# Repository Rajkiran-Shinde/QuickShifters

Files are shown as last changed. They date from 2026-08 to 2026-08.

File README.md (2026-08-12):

# QuickShifter

### A precision-timed QuickShifter controller built from scratch using STM8S003F3P6

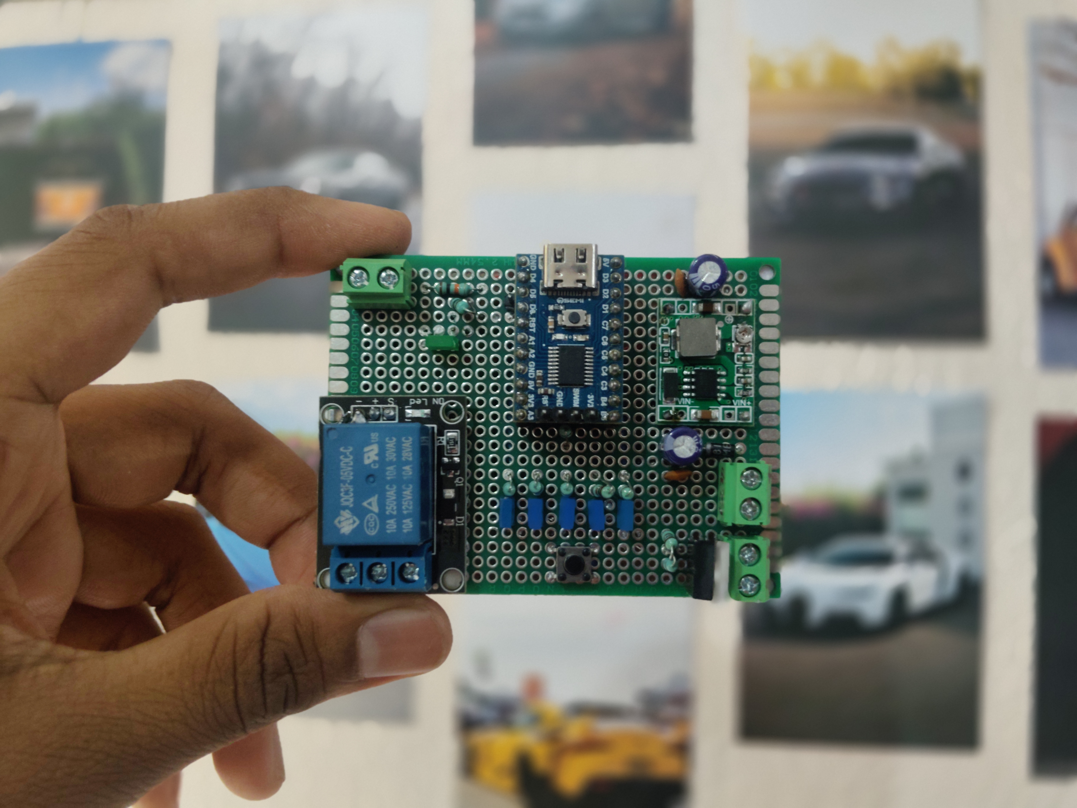
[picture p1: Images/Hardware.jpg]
QuickShifter Hardware


This project started with a simple requirement: build a QuickShifter module that can control a relay for a precisely defined amount of time.

At first, the problem looks almost too simple:

```text
Trigger → Relay ON → Wait → Relay OFF
```

But once the system has to operate reliably on real hardware, timing, switch bounce, repeated triggers, unexpected states, configuration storage, fault recovery, and watchdog behavior all become part of the problem.

This project was built around that idea. Instead of using a blocking delay-based firmware, the QuickShifter was developed as a small, modular embedded system with a timer-driven architecture, state machines, persistent configuration, user feedback, and multiple layers of fault handling.

---

## Project Overview

The QuickShifter uses an **STM8S003F3P6** microcontroller to detect a shift trigger and activate a relay for a selectable cut duration.

Five operating modes are currently available:

| Mode | Cut Time |
| --- | ---: |
| Mode 1 | 40 ms |
| Mode 2 | 50 ms |
| Mode 3 | 60 ms |
| Mode 4 | 70 ms |
| Mode 5 | 80 ms |

The selected mode can be changed using a dedicated button. LEDs indicate the currently selected mode, while a passive buzzer provides audible feedback for startup, mode changes, shifts, ready states, and faults.

The firmware also stores the selected configuration in EEPROM so the selected mode can persist across resets.

The main design goal was to keep the system **small, deterministic, and easy to reason about** rather than using a more powerful microcontroller than the application actually requires.

---

## Hardware

The heart of the system is the **STM8S003F3P6**, running from its internal 16 MHz HSI oscillator. The MCU handles the complete application: input processing, timing, relay control, configuration management, LEDs, buzzer generation, debugging, and watchdog supervision.

The relay is connected to the MCU through the relay-control output and acts as the primary actuator. The shift trigger and mode-selection button use GPIO inputs with internal pull-ups, meaning the inputs remain HIGH when idle and are pulled LOW when the corresponding switch is pressed.

The user interface consists of five individual mode LEDs and a separate RGB status LED. A passive buzzer provides audible feedback and is driven through a BC547 transistor so that the MCU GPIO does not have to directly drive the buzzer load.

The hardware also exposes UART debugging through the STM8 UART1 peripheral. During development, an ESP8266 NodeMCU board was used as a USB-to-UART interface so that debug information could be monitored on a PC.

---

## Hardware Pin Configuration

The current documented hardware allocation is:

| STM8 Pin | Function |
| --- | --- |
| PD2 | Relay output |
| PD3 | QuickShifter trigger input |
| PD4 | Mode-selection button |
| PD5 | UART1 TX |
| PD6 | UART1 RX, currently unused |
| PD6 / A1 / C3 / C4 / C5 | Mode LED outputs as documented in the project |
| PB4 | RGB LED Red |
| PC6 | RGB LED Green |
| PC7 | RGB LED Blue |
| PA3 | Passive buzzer driver |

The exact hardware configuration should always be checked against the latest source files and circuit documentation before building another hardware revision.

---

# Firmware Architecture

The firmware is written in **Embedded C** and is implemented directly around the STM8 peripherals and registers.

There is no Arduino framework involved and no large external firmware framework controlling the application. Hardware functionality is separated into small modules so that the application logic does not need to directly manipulate every peripheral register.

The architecture roughly follows:

```text
                         main()
                           │
                           ▼
                  Application Layer
                           │
              ┌────────────┴────────────┐
              │                         │
              ▼                         ▼
       QuickShifter FSM            Mode Manager
              │                         │
              ├──────────────┐          │
              ▼              ▼          ▼
        Button Driver   Software Timer  EEPROM
              │              │
              └───────┬──────┘
                      ▼
                 Timer Driver
                      │
                      ▼
                   TIM4
                      │
                      ▼
                1 ms System Tick

Additional services:
LED Driver ──► User feedback
Buzzer Driver ──► Audible feedback
UART/Debug ──► Development diagnostics
Watchdog ──► Firmware recovery
```

The main loop is cooperative and non-blocking. Instead of stopping execution for tens of milliseconds while waiting for a relay timer to expire, the firmware starts a software timer and continues executing the rest of the application.

This allows the buttons, state machine, buzzer, and watchdog to continue operating while the relay timing is in progress.

---

# Clock and Timer System

The STM8S003F3 initially operates from its internal **16 MHz HSI oscillator** with a default divider. The firmware configures the clock divider so that the MCU operates at the full 16 MHz.

```c
CLK_CKDIVR = 0x00;
```

The system uses **TIM4** as the main timing foundation.

TIM4 is configured with:

```text
CPU Clock     : 16 MHz
Prescaler     : 128
Timer Clock   : 125 kHz
Auto Reload   : 124
Tick          : 1 ms
```

Every TIM4 update interrupt increments a global system tick.

```c
volatile uint32_t system_tick;
```

This provides a common time reference for the rest of the firmware.

The important idea here is that the QuickShifter does not depend on large blocking delays such as:

```c
Timer_Delay(70);
```

for application timing.

Instead, the firmware can start a timer and check whether it has expired while continuing to execute other tasks.

---

# Software Timer

The software timer module is built on top of the 1 ms system tick.

A software timer contains:

```c
typedef struct
{
    uint32_t start_time;
    uint32_t duration;
    uint8_t active;

} SoftwareTimer_t;
```

The main API is:

```c
SoftwareTimer_Start();
SoftwareTimer_Stop();
SoftwareTimer_Expired();
SoftwareTimer_IsRunning();
```

This allows multiple independent timing operations to exist without requiring a separate hardware timer for every function.

For example, the relay cut timer and cooldown timer can use the same system tick while remaining logically independent.

---

# QuickShifter State Machine

The QuickShifter itself is implemented as a **finite state machine** rather than a collection of unrelated delays and `if` statements.

The normal operating sequence is:

```text
                 ┌──────────────┐
                 │     IDLE     │
                 └──────┬───────┘
                        │
                  Shift detected
                        │
                        ▼
                 ┌──────────────┐
                 │ CUT_ACTIVE   │
                 └──────┬───────┘
                        │
                   Timer expires
                        │
                        ▼
                 ┌──────────────┐
                 │  COOLDOWN    │
                 └──────┬───────┘
                        │
                 Cooldown expires
                        │
                        ▼
                 ┌──────────────┐
                 │ WAIT_RELEASE │
                 └──────┬───────┘
                        │
                  Button released
                        │
                        ▼
                 ┌──────────────┐
                 │     IDLE     │
                 └──────────────┘
```

The firmware also contains fault handling that forces the system toward a known safe condition.

The main QuickShifter task is implemented through:

```c
QuickShifter_Init();
QuickShifter_Task();
```

When a valid shift is detected, the relay is activated and the selected cut-time timer is started.

When that timer expires, the relay is explicitly turned OFF.

After that, the firmware enters a cooldown period before waiting for the original trigger to be released.

This prevents one long button press or mechanical vibration from producing multiple cuts.

The important safety principle throughout the state machine is:

```text
Unexpected condition
        ↓
    Relay OFF
        ↓
  Known firmware state
```

---

# Button Driver

Mechanical buttons do not produce a perfectly clean HIGH-to-LOW transition. They bounce electrically for a short period when pressed or released.

The button driver therefore uses its own state machine:

```text
RELEASED
    │
    ▼
DEBOUNCE_PRESS
    │
    ▼
PRESSED
    │
    ▼
DEBOUNCE_RELEASE
    │
    ▼
RELEASED
```

A software timer is used for the debounce period rather than blocking the CPU.

The button module provides:

```c
Button_Init();
Button_Update();
Button_GetPress();

ModeButton_Init();
ModeButton_Update();
ModeButton_GetPress();
```

The driver also converts a physical press into a one-shot logical event. This means one physical button press produces one application event instead of repeatedly triggering the QuickShifter while the button remains pressed.

---

# Operating Modes

The QuickShifter supports five selectable cut durations:

```text
Mode 1 → 40 ms
Mode 2 → 50 ms
Mode 3 → 60 ms
Mode 4 → 70 ms
Mode 5 → 80 ms
```

The mode manager is implemented in:

```text
mode.c
mode.h
```

The main functions are:

```c
Mode_Init();
Mode_Next();
Mode_Get();
Mode_GetCutTime();
```

The modes wrap around continuously:

```text
Mode 1
  ↓
Mode 2
  ↓
Mode 3
  ↓
Mode 4
  ↓
Mode 5
  ↓
Mode 1
```

The selected mode is kept separate from the actual timer implementation. The mode manager decides **what timing should be used**, while the timer system is responsible for **measuring that timing**.

This separation makes the firmware easier to modify and test.

---

# EEPROM Configuration

The selected mode is stored in the STM8 EEPROM so that configuration can persist between resets.

The EEPROM implementation does more than simply write a number and hope for the best.

The configuration contains a magic value, mode value, and checksum. The firmware validates the stored information before accepting it.

Conceptually:

```text
Read EEPROM
     │
     ├── Magic
     ├── Mode
     └── Checksum
           │
           ▼
      Validate data
           │
      ┌────┴────┐
      ▼         ▼
   Valid      Invalid
      │         │
      ▼         ▼
   Accept    Default mode
```

The checksum is calculated from the stored configuration, allowing simple data corruption to be detected.

The firmware also verifies EEPROM writes by reading the data back after programming.

An important part of the implementation is that the watchdog remains active during blocking EEPROM operations. Instead of disabling the watchdog while EEPROM operations are taking place, the EEPROM driver services the watchdog during the operation.

---

# Watchdog and Fault Handling

The STM8 Independent Watchdog provides a final recovery mechanism if the firmware becomes stuck.

The application initializes and refreshes it using:

```c
Watchdog_Init();
Watchdog_Refresh();
```

The normal main loop continuously refreshes the watchdog.

If the firmware becomes trapped in an unexpected infinite loop or otherwise stops servicing the watchdog, the IWDG eventually resets the MCU.

The watchdog is not being used as a replacement for proper firmware design. It is the last line of defense against firmware execution failure.

The project also includes deliberate watchdog fault-injection testing where watchdog refreshing was intentionally stopped to verify that the MCU actually resets.

Another important detail is that blocking EEPROM and UART operations were made watchdog-aware. This prevents legitimate lengthy operations from accidentally causing a watchdog reset while still allowing the watchdog to recover the system from a genuine firmware lock-up.

---

# LED Driver

The LED subsystem provides visual feedback without requiring an external GPIO expander.

Five LEDs represent the five QuickShifter modes:

```text
Mode 1 → 40 ms
Mode 2 → 50 ms
Mode 3 → 60 ms
Mode 4 → 70 ms
Mode 5 → 80 ms
```

The LED functionality is contained in:

```text
led.c
led.h
```

The main interface includes:

```c
LED_Init();
LED_Mode_Display();
```

A separate RGB LED provides system-level status indication.

The RGB channels are controlled directly through STM8 GPIO pins, keeping the implementation simple and deterministic.

---

# Passive Buzzer

The project uses a **passive buzzer** rather than simply switching an active buzzer ON and OFF.

A passive buzzer requires an alternating waveform, so the firmware generates a square wave whose frequency determines the perceived pitch.

The final design uses a **BC547 NPN transistor** as a low-side driver between the MCU and the buzzer.

```text
STM8 GPIO
    │
   1 kΩ
    │
 BC547 Base
    │
 BC547 Collector
    │
 Passive Buzzer
    │
   +5V
```

The buzzer waveform is generated using **TIM2**. The timer interrupt toggles the buzzer output, producing the required square wave.

The buzzer software also contains a small melody engine based on notes containing:

```c
frequency
duration
```

This allows events such as startup, mode changes, quick shifts, ready status, and faults to have their own audible feedback.

The melody engine is designed to be non-blocking so that audio feedback does not interfere with the QuickShifter timing logic.

The main buzzer functions include:

```c
Buzzer_Init();
Buzzer_Play();
Buzzer_Task();
Buzzer_TickISR();
```

---

# UART Debugging

During development, UART was added to make firmware behavior easier to observe.

The debug architecture is separated into two layers:

```text
Application
    ↓
debug.c / debug.h
    ↓
uart.c / uart.h
    ↓
STM8 UART1
```

This means application code can use:

```c
Debug_Log();
Debug_LogState();
Debug_LogShift();
Debug_LogMode();
```

without directly accessing UART registers.

The current UART debug configuration is:

```text
Baud Rate : 9600
Data      : 8 bits
Parity    : None
Stop      : 1
```

UART debugging was tested using an ESP8266 NodeMCU board as a temporary USB-to-UART interface and monitored on a PC.

Debugging can also be disabled for a production build using the debug configuration macro, allowing the application to remain independent from the development UART interface.

---

# Main Application Flow

The main application initializes the system in a controlled sequence:

```text
Clock
  ↓
Timer
  ↓
Buttons
  ↓
Mode Button
  ↓
Debug
  ↓
LED
  ↓
Buzzer
  ↓
EEPROM
  ↓
Mode
  ↓
QuickShifter
  ↓
Watchdog
  ↓
Main Loop
```

The main loop then continuously services the different modules:

```c
while(1)
{
    Button_Update();
    ModeButton_Update();

    QuickShifter_Task();

    Buzzer_Task();

    Watchdog_Refresh();
}
```

Mode changes are handled as events. When a valid mode-button press is detected, the firmware advances to the next mode, updates the mode LED, plays the corresponding buzzer feedback, and reports the new configuration through the debug interface when debugging is enabled.

---

# Software Stack

The project is intentionally lightweight and close to the hardware.

**Language:** Embedded C

**Target MCU:** STM8S003F3P6

**Clock:** 16 MHz internal HSI

**Hardware peripherals:** GPIO, TIM4, TIM2, UART1, EEPROM, Independent Watchdog

**Firmware architecture:** Modular, cooperative, non-blocking application with finite state machines and software timers

**Debug interface:** UART1 → USB-UART → PC

**User interface:** Push buttons, five mode LEDs, RGB status LED and passive buzzer

The repository contains the STM8 development project files and the complete C/H source modules used to implement the firmware.

---

# Source Code Structure

The repository is divided into small modules instead of keeping the complete firmware inside `main.c`.

```text
QuickShifters/
│
├── images/
│   └── Hardware.jpg
│
├── main.c
│
├── gpio.c / gpio.h
├── clock.c / clock.h
├── timer.c / timer.h
├── software_timer.c / software_timer.h
│
├── button.c / button.h
├── quickshifter.c / quickshifter.h
├── mode.c / mode.h
│
├── relay.c / relay.h
├── led.c / led.h
├── buzzer.c / buzzer.h
│
├── eeprom.c / eeprom.h
├── watchdog.c / watchdog.h
│
├── uart.c / uart.h
├── debug.c / debug.h
│
├── stm8_hw.h
├── stm8_interrupt_vector.c
├── common.h
├── config.h
│
├── 01_GPIO.md
├── 02_stateMachine.md
├── 03_ModeSelection.md
├── 04_firmwareSafety.md
├── 05_led&Buzzer_Driver.md
└── pin_config.md
```

The individual modules have clear responsibilities.

`quickshifter.c` contains the core QuickShifter state machine. `button.c` handles physical input and debouncing. `mode.c` handles the five operating modes. `software_timer.c` provides reusable timing functionality on top of the system tick.

`relay.c`, `led.c`, and `buzzer.c` handle the physical outputs, while `eeprom.c` manages persistent configuration. `watchdog.c` handles the Independent Watchdog and `debug.c`/`uart.c` provide the development-time debugging interface.

This separation keeps the application logic independent from most low-level hardware details.

---

# Important Firmware APIs

Some of the main interfaces exposed by the firmware are:

```c
// Clock
CLK_Init();

// Timer
Timer_Init();
Timer_GetTick();
Timer_Delay();

// Software Timer
SoftwareTimer_Start();
SoftwareTimer_Stop();
SoftwareTimer_Expired();
SoftwareTimer_IsRunning();

// Buttons
Button_Init();
Button_Update();
Button_GetPress();

ModeButton_Init();
ModeButton_Update();
ModeButton_GetPress();

// QuickShifter
QuickShifter_Init();
QuickShifter_Task();

// Modes
Mode_Init();
Mode_Next();
Mode_Get();
Mode_GetCutTime();

// EEPROM
EEPROM_Init();

// LEDs
LED_Init();
LED_Mode_Display();

// Buzzer
Buzzer_Init();
Buzzer_Play();
Buzzer_Task();
Buzzer_TickISR();

// Watchdog
Watchdog_Init();
Watchdog_Refresh();

// Debug
Debug_Init();
Debug_Log();
Debug_LogState();
Debug_LogShift();
Debug_LogMode();
```

These interfaces allow the application layer to interact with the hardware modules without directly depending on their internal implementation.

---

# Safety Philosophy

The most important design rule in the firmware is simple:

> **If something unexpected happens, the relay should end up OFF.**

This principle appears in multiple places in the firmware.

During startup, the relay is initialized into a known state. During normal operation, the relay is explicitly turned OFF when the cut timer expires. During invalid state recovery, the relay is also forced OFF before the state machine returns to a known state.

Other layers provide additional protection:

```text
Button noise
    ↓
Debounce

Repeated trigger
    ↓
One-shot event + state machine

Relay timing
    ↓
Software timer

Rapid retriggering
    ↓
Cooldown

Held trigger
    ↓
WAIT_RELEASE

Invalid configuration
    ↓
EEPROM validation

Firmware lock-up
    ↓
Independent Watchdog
```

The intention is not to make the firmware complicated for the sake of complexity. Each layer exists because it solves a different failure mode.

---

# Development and Testing

The firmware was developed incrementally rather than attempting to build the complete system in one step.

The initial hardware verified basic GPIO operation and relay control. The firmware was then moved from blocking delays to a timer-driven architecture. TIM4 was verified using the system tick, and the software timer system was introduced.

The QuickShifter state machine and non-blocking button driver were then added, followed by the five configurable modes and EEPROM persistence.

UART debugging was added to make development and troubleshooting easier. The LED and buzzer system was developed separately and integrated into the main application afterward.

The watchdog was also tested through deliberate fault injection to confirm that a firmware execution failure results in an MCU reset.

During development, several real hardware/firmware issues were encountered and resolved, including GPIO abstraction problems, buzzer drive limitations, timer/interrupt behavior, EEPROM interaction with the watchdog, and UART debugging configuration.

This repository contains the development notes documenting those stages in more detail.

---

# Documentation

The project includes dedicated documentation for the major firmware subsystems:

* [`01_GPIO.md`](01_GPIO.md) — GPIO abstraction and hardware configuration
* [`02_stateMachine.md`](02_stateMachine.md) — Timer architecture, software timers, state machines and non-blocking firmware
* [`03_ModeSelection.md`](03_ModeSelection.md) — UART debugging, mode selection and configurable timing
* [`04_firmwareSafety.md`](04_firmwareSafety.md) — Safety, EEPROM validation, watchdog and fault handling
* [`05_led&Buzzer_Driver.md`](05_led%26Buzzer_Driver.md) — LED and passive buzzer architecture
* [`pin_config.md`](pin_config.md) — Hardware pin allocation

These documents provide a deeper look into how the firmware evolved and why particular implementation decisions were made.

---

# What Makes This Project Interesting?

The interesting part of this project isn't really the relay.

It's the engineering around it.

The system takes a simple real-world requirement and turns it into a small embedded architecture with deterministic timing, state-based control, persistent configuration, hardware feedback, debugging infrastructure and recovery mechanisms.

Instead of:

```text
Button
  ↓
delay()
  ↓
Relay
```

the final architecture is closer to:

```text
Physical Input
      ↓
Debounce State Machine
      ↓
One-Shot Event
      ↓
QuickShifter State Machine
      ↓
Software Timer
      ↓
Relay Control
      ↓
Cooldown
      ↓
Wait for Release
      ↓
Ready for Next Shift
```

And running alongside it are the watchdog, configuration system, LEDs, buzzer and debug infrastructure.

That was the main goal of the project: **not just making the relay work, but making the system behave predictably when the real world inevitably does something unexpected.**

---

# Current Status

The first working prototype has been developed and the core firmware architecture is operational.

The current implementation includes the five selectable cut modes, non-blocking timing, QuickShifter and button state machines, EEPROM configuration, watchdog supervision, LED feedback, buzzer feedback and UART debugging.

Further hardware refinement, validation and production-oriented improvements can be added as the project moves beyond the prototype stage.

---

## Author

**Rajkiran Shinde**

Embedded Systems | Firmware | Electronics

[GitHub](https://github.com/Rajkiran-Shinde)
---

## Disclaimer

This repository documents an embedded prototype developed for a real-world application. The firmware and hardware should be validated thoroughly against the final electrical and mechanical system before being used in a safety-critical or production environment.

---

### Built with C, registers, timers, state machines... and a questionable amount of debugging. 😄

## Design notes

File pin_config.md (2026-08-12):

PD2 ----> Relay output 
PD3 ----> Trigger input (D3 to GND)
PD4 ----> Mode Selection pin (D4--GND)
PD5 ----> UART1 TX 

Mode LED's 
Mode 1 --> D6
Mode 2 --> A1
Mode 3 --> C3
Mode 4 --> C4
Mode 5 --> C5

System Led 
Red --> B4
Green --> C6
Blue --> C7

Buzzer --> A32

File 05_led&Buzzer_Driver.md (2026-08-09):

# QuickShifter — LED Driver & Buzzer Driver Documentation

## 1. Overview

The QuickShifter firmware uses two independent user-interface subsystems:

1. **LED Driver**

   * Displays the currently selected QuickShifter mode.
   * Provides system/status indication.
   * Uses discrete GPIO outputs rather than an external I/O expander.

2. **Buzzer Driver**

   * Provides audible feedback during system startup.
   * Indicates QuickShifter mode changes.
   * Provides audible feedback when a quick-shift is detected.
   * Provides ready/fault indication.
   * Uses a passive buzzer driven through a **BC547 transistor**.
   * Generates tones using **TIM2** and software-controlled GPIO toggling.
   * Uses a non-blocking melody engine so audio feedback does not interfere with QuickShifter timing.

The design was intentionally kept lightweight and deterministic because the QuickShifter's primary function is timing-critical relay control.

---

# 2. LED Driver

## 2.1 Design Objective

The LED subsystem was designed to provide visual feedback without introducing an external GPIO expander such as the MCP23008.

Initially, an I/O expander and LED matrix were considered because the system contains multiple LEDs.

The final architecture uses the STM8 GPIO pins directly.

This was selected because:

* The number of required outputs was manageable.
* The LEDs can operate from the MCU's logic voltage with appropriate current limiting.
* An external I/O expander would add unnecessary hardware and software complexity.
* A 3×3 LED matrix would require additional scanning logic and six GPIO pins while only providing limited savings.
* Direct GPIO control provides simpler and more deterministic firmware.

---

# 3. LED Hardware Architecture

The system contains:

### Mode LEDs

Five LEDs are used to represent the five QuickShifter modes:

| LED | Function |
| --- | --- |
| Mode LED 1 | 40 ms |
| Mode LED 2 | 50 ms |
| Mode LED 3 | 60 ms |
| Mode LED 4 | 70 ms |
| Mode LED 5 | 80 ms |

The selected mode is displayed by activating the corresponding LED.

The mode timing relationship is:

```text
Mode 1 ? 40 ms
Mode 2 ? 50 ms
Mode 3 ? 60 ms
Mode 4 ? 70 ms
Mode 5 ? 80 ms
```

This gives the user an immediate visual indication of the selected cut duration.

---

# 4. Status RGB LED

A separate RGB LED provides overall system status.

The final GPIO mapping is:

```text
RED   ? PB4
GREEN ? PC6
BLUE  ? PC7
```

This LED is independent of the five mode LEDs.

It can therefore be used for system-level states such as:

```text
OFF      ? System inactive / no status
RED      ? Fault / error
GREEN    ? Ready / normal
BLUE     ? System or operating indication
```

The exact status-state mapping can be extended later without changing the basic driver architecture.

---

# 5. LED Driver Software Architecture

The LED functionality was consolidated into:

```text
led.h
led.c
```

rather than creating separate files such as:

```text
mode_led.c
status_led.c
```

This was intentionally done because both are fundamentally GPIO-based LED functions.

The architecture is therefore:

```text
                LED DRIVER
                    ¦
          +-------------------+
          ¦                   ¦
      Mode LEDs          Status RGB LED
          ¦                   ¦
      5 outputs          R / G / B
```

---

# 6. LED Initialization

The LED driver contains an initialization routine:

```c
LED_Init();
```

This configures all LED GPIO pins as outputs and establishes a known initial state.

The initialization sequence is performed during system startup.

Conceptually:

```text
MCU Reset
   ?
Clock initialization
   ?
Timer initialization
   ?
Button initialization
   ?
LED_Init()
   ?
LED outputs configured
```

This prevents the LEDs from remaining in an undefined state after reset.

---

# 7. Mode LED Display

The mode LED driver provides a function similar to:

```c
LED_Mode_Display(mode);
```

The mode number is converted into the corresponding LED output.

For example:

```text
LED_Mode_Display(1)
       ?
Mode 1 LED ON
```

and:

```text
LED_Mode_Display(5)
       ?
Mode 5 LED ON
```

The selected mode is therefore directly visible to the user.

---

# 8. Mode Selection Integration

The mode display is updated whenever the mode button produces a valid press event.

The main application follows this sequence:

```text
Mode button pressed
        ?
Debounce
        ?
ModeButton_GetPress()
        ?
Mode_Next()
        ?
LED_Mode_Display()
        ?
Buzzer_Play(MODE_CHANGE)
```

This creates a combined visual + audible user interface.

---

# 9. GPIO Port A Issue Discovered During Development

One important debugging issue occurred while implementing the buzzer and GPIO abstraction.

The initial GPIO driver supported:

```text
PORT_B
PORT_C
PORT_D
```

but did not correctly implement:

```text
PORT_A
```

When the buzzer was moved to PA3, the GPIO abstraction did not correctly map the Port A registers.

The result was that a request such as:

```c
GPIO_Output_PP(PORT_A, PIN3);
```

did not actually configure the PA3 registers correctly.

This caused PA3 not to reach the expected output voltage.

The issue was solved by adding the STM8S003F3 Port A registers:

```text
PA_ODR
PA_IDR
PA_DDR
PA_CR1
PA_CR2
```

and adding `PORT_A` handling to the GPIO register-selection functions.

This was an important firmware-level hardware abstraction bug.

---

# 10. Buzzer Driver

## 10.1 Objective

The buzzer subsystem was designed to provide an audible interface without blocking the QuickShifter control loop.

The required events were:

* Boot
* Mode change
* Quick shift
* Ready
* Fault

Instead of simply turning the buzzer ON/OFF for arbitrary delays, a reusable **melody engine** was implemented.

---

# 11. Passive Buzzer

The project uses a:

```text
Passive buzzer
```

A passive buzzer requires an alternating electrical signal.

Therefore, the STM8 does not simply set the buzzer GPIO HIGH.

Instead, the firmware generates a square wave.

For example:

```text
       +-----+     +-----+
HIGH   ¦     ¦     ¦     ¦
       ¦     ¦     ¦     ¦
LOW ---+     +-----+     +-----
```

The frequency of this waveform determines the perceived pitch.

---

# 12. Initial Direct GPIO Buzzer Drive

Initially, the passive buzzer was connected directly to the STM8 GPIO.

This worked electrically, but the output volume was very low.

The same buzzer was then tested using an Arduino Uno.

The Arduino produced significantly louder sound.

This demonstrated that:

```text
Buzzer itself ? functional
```

and the problem was related to the STM8-side drive.

---

# 13. BC547 Driver

To solve the low-volume problem, a BC547 NPN transistor was added as a low-side driver.

The final architecture is:

```text
                  +5V
                   ¦
                   ¦
               Passive
                Buzzer
                   ¦
                   ¦
                   C
                +-----+
STM8 PA3 --1k--?¦ B   ¦
                ¦BC547¦
                ¦     ¦
                +--E--+
                   ¦
                  GND
```

The STM8 does **not** directly power the buzzer anymore.

Instead:

```text
PA3
 ?
1 kO resistor
 ?
BC547 base
 ?
BC547 switches buzzer current
```

The transistor therefore isolates the MCU GPIO from the buzzer load and provides significantly stronger drive.

---

# 14. Common Ground

The STM8 and buzzer supply must share a common ground:

```text
STM8 GND
   ¦
   +-------- Buzzer supply GND
   ¦
   +-------- BC547 emitter
```

Without a common reference, the transistor control signal would not have a reliable voltage reference.

---

# 15. Buzzer GPIO

The final buzzer GPIO is:

```text
PA3
```

The configuration is:

```c
#define BUZZER_PORT    PORT_A
#define BUZZER_PIN     PIN3
```

PA3 is configured as a push-pull output.

The signal from PA3 drives the BC547 base through the base resistor.

---

# 16. Why PB5 Was Abandoned

The buzzer was initially tested using PB5.

However, PB5 on the STM8S003F3 is a true open-drain pin.

That made it unsuitable for the direct push-pull buzzer waveform we wanted.

Therefore, the buzzer was moved to:

```text
PA3
```

and configured as a push-pull output.

This was a hardware-specific STM8 pin-selection decision.

---

# 17. TIM2 Tone Generation

The buzzer uses **TIM2** to generate its waveform.

The STM8 system clock is operating at:

```text
16 MHz
```

TIM2 is configured with a prescaler of:

```text
/8
```

Therefore:

```text
16 MHz / 8 = 2 MHz
```

timer clock.

The buzzer GPIO is toggled once per timer overflow.

Therefore the output frequency is approximately:

```text
Fout = TimerClock / (2 × ARR)
```

or:

```text
Fout = 2,000,000 / (2 × ARR)
```

This produces the required audible square wave.

---

# 18. TIM2 Interrupt Architecture

TIM2 generates an update interrupt.

The interrupt vector is:

```c
INTERRUPT_HANDLER(
    TIM2_UPD_OVF_BRK_IRQHandler,
    13
)
{
    Buzzer_TickISR();
}
```

The architecture is:

```text
TIM2 overflow
      ?
TIM2 interrupt
      ?
IRQ 13
      ?
Buzzer_TickISR()
      ?
Clear interrupt flag
      ?
Toggle PA3
      ?
BC547
      ?
Passive buzzer
```

---

# 19. Important TIM2 Watchdog Issue

During development, enabling the TIM2 interrupt initially caused the STM8 watchdog to reset the MCU.

The debugging process isolated the problem.

The following test worked:

```c
TIM2_IER |= TIM2_IER_UIE;
```

while the ISR only cleared the TIM2 update flag.

This confirmed that:

* TIM2 configuration was functional.
* TIM2 was running.
* The interrupt was reaching the MCU.
* The interrupt flag could be cleared.
* The watchdog problem was related to the original ISR/output handling rather than TIM2 itself.

The final ISR became:

```c
void Buzzer_TickISR(void)
{
    TIM2_SR1 &= (uint8_t)(~TIM2_SR_UIF);

    GPIO_Toggle(
        BUZZER_PORT,
        BUZZER_PIN
    );
}
```

This successfully generates the buzzer waveform.

---

# 20. Buzzer Melody Engine

Instead of hardcoding delays, the buzzer uses a note structure:

```c
typedef struct
{
    uint16_t frequency;
    uint16_t duration;

} BuzzerNote;
```

Each note contains:

```text
frequency
duration
```

For example:

```c
{ 800, 100 }
```

means:

```text
800 Hz
100 ms
```

---

# 21. REST and End Markers

Two special values are used.

### REST

```c
#define BUZZER_REST 0
```

A REST means:

```text
No sound
```

The timer is stopped and the buzzer output is forced LOW.

### End of melody

```c
#define BUZZER_MELODY_END 0xFFFF
```

This tells the melody engine that the sequence has finished.

---

# 22. Current Tone Range

After testing several frequencies, the current preferred range was established as:

```c
#define TONE_LOW   800
#define TONE_MID   1000
#define TONE_HIGH  1200
```

This range was selected based on actual listening tests with the installed buzzer and BC547 driver.

Higher frequencies such as:

```text
1800 Hz
2200 Hz
2600 Hz
3000+ Hz
```

were found to sound sharper and more aggressive.

The 800–1200 Hz range provides a more comfortable sound for this application.

---

# 23. Boot Melody

The boot melody follows the original musical concept developed during the project.

Current sequence:

```text
800 Hz
   ?
1000 Hz
   ?
1200 Hz
   ?
1000 Hz
```

It provides a rising startup signature followed by a settling tone.

Conceptually:

```text
DO ? MID ? HIGH ? MID
```

---

# 24. Mode Change Melody

The mode-change melody is:

```text
1000 Hz
   ?
1200 Hz
```

It provides a short confirmation that the selected QuickShifter mode has changed.

The mode change therefore provides:

```text
Button press
     ?
Mode changes
     ?
Mode LED changes
     ?
Buzzer confirmation
```

---

# 25. QuickShift Melody

The QuickShift beep is deliberately short.

The current implementation uses:

```text
1200 Hz
˜45 ms
```

This produces a short audible confirmation when the shift input is detected.

---

# 26. QuickShift Integration

The buzzer was integrated into `quickshifter.c`.

When a valid shift event is detected:

```c
if(Button_GetPress())
{
    Buzzer_Play(BUZZER_EVENT_SHIFT);

    Relay_On();

    ...
}
```

The important design decision is that **the buzzer does not delay the relay operation**.

The sequence is:

```text
Valid shift detected
       ¦
       +--------? Start buzzer
       ¦
       +--------? Relay ON
                       ¦
                       ?
                  40–80 ms cut
```

The buzzer operates independently using TIM2 and the non-blocking melody engine.

---

# 27. Non-Blocking Buzzer Architecture

This is one of the most important design decisions.

The firmware does **not** use:

```c
delay(40);
```

or:

```c
for(...)
{
    // wait
}
```

to generate sound.

Instead:

```c
Buzzer_Play(...)
```

starts the sound and immediately returns.

Then:

```c
Buzzer_Task();
```

is called continuously from the main loop.

Therefore:

```text
Buzzer_Play()
     ?
Set state
     ?
Start TIM2
     ?
RETURN
```

while:

```text
Main loop
    ?
Buzzer_Task()
    ?
Check elapsed time
    ?
Move to next note
```

This keeps the system responsive.

---

# 28. Why This Is Important for QuickShifter

The QuickShifter timing is:

```text
Mode 1 ? 40 ms
Mode 2 ? 50 ms
Mode 3 ? 60 ms
Mode 4 ? 70 ms
Mode 5 ? 80 ms
```

These timings are safety/function-critical.

The buzzer must therefore **never become part of the relay timing path**.

The final architecture keeps them independent:

```text
              MAIN LOOP
                  ¦
       +---------------------+
       ¦                     ¦
 QuickShifter             Buzzer
       ¦                     ¦
 Relay timing            TIM2 timing
       ¦                     ¦
 40–80 ms cut            Audio waveform
```

---

# 29. Buzzer State

The driver maintains:

```c
static const BuzzerNote *current_melody;
static uint8_t current_note;
static uint32_t note_start_time;
static uint8_t buzzer_busy;
```

These variables allow the melody engine to know:

* Which melody is playing.
* Which note is active.
* When that note started.
* Whether the buzzer is currently active.

---

# 30. Buzzer Event Interface

The application does not directly manipulate TIM2.

Instead it uses:

```c
Buzzer_Play(BUZZER_EVENT_BOOT);
```

or:

```c
Buzzer_Play(BUZZER_EVENT_MODE_CHANGE);
```

or:

```c
Buzzer_Play(BUZZER_EVENT_SHIFT);
```

This creates a clean abstraction:

```text
Application
    ¦
    ?
Buzzer_Play(EVENT)
    ¦
    ?
Melody Engine
    ¦
    ?
TIM2
    ¦
    ?
GPIO
    ¦
    ?
BC547
    ¦
    ?
Buzzer
```

---

# 31. Main Application Integration

The main initialization sequence includes:

```c
LED_Init();

Buzzer_Init();

EEPROM_Init();

Mode_Init();

LED_Mode_Display(
    Mode_Get() + 1
);

QuickShifter_Init();

Buzzer_Play(
    BUZZER_EVENT_BOOT
);
```

The boot melody therefore plays after the system has initialized its major subsystems.

---

# 32. Main Loop Integration

The main loop continuously services the buzzer:

```c
Buzzer_Task();
```

This must remain in the main loop because the melody timing is software-managed.

The general architecture is:

```text
while(1)
{
    Button_Update();

    ModeButton_Update();

    Mode event handling

    QuickShifter_Task();

    Buzzer_Task();

    Watchdog_Refresh();
}
```

---

# 33. Current User Interface

The QuickShifter now has three feedback mechanisms:

### Mode LEDs

```text
Mode 1 ? 40 ms
Mode 2 ? 50 ms
Mode 3 ? 60 ms
Mode 4 ? 70 ms
Mode 5 ? 80 ms
```

### RGB status LED

```text
Red
Green
Blue
```

for system-level indication.

### Buzzer

```text
Boot
Mode change
Quick shift
Ready
Fault
```

This gives the project a complete embedded-system user interface.

---

# 34. Final Hardware Architecture

The current relevant architecture is:

```text
                    STM8S003F3
                         ¦
          +--------------+--------------+
          ¦              ¦              ¦
       Mode LEDs      Status RGB       PA3
          ¦              ¦              ¦
          ¦              ¦             1kO
          ¦              ¦              ¦
          ¦              ¦              ?
          ¦              ¦           BC547
          ¦              ¦              ¦
          ¦              ¦              ?
          ¦              ¦        Passive Buzzer
          ¦              ¦              ¦
          ¦              ¦             +5V
          ¦              ¦
          +---------------------------------
```

The exact mode/status GPIO mappings are maintained in `config.h` and the LED driver.

---

# 35. Engineering Principles Used

The LED and buzzer implementation follows several important embedded-system principles.

### 1. Hardware abstraction

Application code does not directly manipulate LED registers.

Instead:

```c
LED_Mode_Display();
```

is used.

Likewise, the application does not directly configure TIM2 for every sound.

It uses:

```c
Buzzer_Play();
```

---

### 2. Non-blocking design

No blocking delays are used for melody playback.

This preserves QuickShifter responsiveness.

---

### 3. Event-driven architecture

The system reacts to events:

```text
Boot event
Mode event
Shift event
Ready event
Fault event
```

rather than continuously polling the buzzer state for application decisions.

---

### 4. Deterministic timing

TIM2 generates the actual audio waveform.

The system timer continues to provide the millisecond timing used by the rest of the firmware.

---

### 5. Separation of responsibilities

```text
LED Driver
    ? visual feedback

Buzzer Driver
    ? audio feedback

QuickShifter Driver
    ? relay timing

Button Driver
    ? input/debounce

Mode Driver
    ? mode management

Timer Driver
    ? system timing
```

Each subsystem has a clearly defined responsibility.

---

# 36. Major Debugging Lessons

Several real hardware/firmware issues were identified while implementing these drivers.

### Issue 1 — LED GPIO resource planning

We considered:

```text
GPIO expander
LED matrix
Direct GPIO
```

and ultimately selected direct GPIO because the available STM8 pins were sufficient.

---

### Issue 2 — PB5 unsuitable for direct buzzer drive

PB5's open-drain characteristics made it unsuitable for the intended direct push-pull waveform.

The buzzer was moved to PA3.

---

### Issue 3 — Port A missing from GPIO abstraction

The GPIO driver did not initially implement Port A correctly.

This caused PA3 configuration failures.

Port A support was added to the GPIO abstraction.

---

### Issue 4 — Buzzer output was too quiet

Direct STM8 GPIO drive produced very low acoustic output.

Testing the same buzzer with Arduino Uno confirmed the buzzer itself was functional.

A BC547 transistor driver was then added.

Result:

```text
STM8 direct drive ? very quiet
BC547 driver      ? significantly louder
```

---

### Issue 5 — TIM2 interrupt/watchdog reset

Enabling the buzzer timer interrupt initially caused watchdog resets.

The issue was isolated through incremental testing:

```text
Buzzer disabled
      ?
No reset

Buzzer enabled
      ?
Reset

TIM2 interrupt enabled
      ?
Test ISR

Clear flag only
      ?
Stable

GPIO toggle added
      ?
Stable
```

This demonstrated the importance of isolating one subsystem at a time when debugging embedded firmware.

---

# 37. Final Driver Files

The resulting software organization is:

```text
QuickShifter/
¦
+-- led.c
+-- led.h
¦
+-- buzzer.c
+-- buzzer.h
¦
+-- gpio.c
+-- gpio.h
¦
+-- button.c
+-- button.h
¦
+-- mode.c
+-- mode.h
¦
+-- quickshifter.c
+-- quickshifter.h
¦
+-- timer.c
+-- timer.h
¦
+-- config.h
```

The LED and buzzer drivers are therefore independent modules that can be reused or modified without restructuring the QuickShifter state machine.

---

# 38. Current Final Behavior

The complete user experience is now:

```text
                    POWER ON
                       ¦
                       ?
                 System Initialize
                       ¦
                       ?
                 LED Status Setup
                       ¦
                       ?
                  ?? BOOT TUNE
                       ¦
                       ?
                Current Mode LED
                       ¦
                       ?
                 SYSTEM READY
                       ¦
             +-------------------+
             ¦                   ¦
        MODE BUTTON          SHIFT INPUT
             ¦                   ¦
             ?                   ?
        Mode_Next()         Buzzer_Play()
             ¦                   ¦
             ?                   ?
        Mode LED update       Relay ON
             ¦                   ¦
             ?                   ?
        Mode beep             40–80 ms
                                 ¦
                                 ?
                            Relay OFF
```

The buzzer and LEDs are therefore not merely decorative additions. They are now part of the **embedded system's user-interface and diagnostic architecture**, while remaining isolated from the safety-critical relay timing.

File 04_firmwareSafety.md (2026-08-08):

# QuickShifter Firmware Safety & Robustness Architecture

## 1. Overview

The QuickShifter firmware was not designed as a simple:

```text
Button → Relay ON → Delay → Relay OFF
```

Instead, the firmware has gradually been developed into a **layered safety architecture**.

The purpose of these safety mechanisms is to ensure that:

* electrical inputs do not accidentally trigger the system,
* button noise does not create false shifts,
* the relay is never intentionally held ON longer than the selected cut duration,
* repeated button presses cannot continuously retrigger the relay,
* invalid firmware states force the relay OFF,
* invalid EEPROM data cannot directly control the system,
* saved configuration is verified before being accepted,
* blocking EEPROM/UART operations do not accidentally trigger the watchdog,
* and a genuine firmware lock-up results in an automatic MCU reset.

The resulting architecture is:

```text
                       QUICKSHIFTER
                            │
             ┌──────────────┼──────────────┐
             │              │              │
             ▼              ▼              ▼
        Input Safety    Timing Safety   Data Safety
             │              │              │
             ▼              ▼              ▼
         Debounce      Cut Timer       EEPROM
         State Machine  Cooldown       Checksum
             │              │           Validation
             │              │              │
             └──────────────┼──────────────┘
                            │
                            ▼
                     Firmware Safety
                            │
                            ▼
                       Watchdog IWDG
                            │
                            ▼
                         MCU RESET
```

---

# 2. Safety Philosophy

The main design principle is:

> **Whenever something unexpected happens, the safest state of the QuickShifter is RELAY OFF.**

The relay is the actuator that actually performs the ignition/fuel cut function.

Therefore, the firmware treats the relay as the critical output.

The basic safety invariant is:

```text
Unexpected condition
        ↓
Relay OFF
```

This principle appears throughout the state machine.

For example, during initialization the QuickShifter starts in:

```c
currentState = QS_STATE_IDLE;
```

and relay initialization is performed before entering normal operation. 

An invalid state also explicitly forces:

```c
Relay_Off();
```

before returning to a known state. 

---

# 3. Safety Layer 1 — GPIO Initialization

Before any QuickShifter logic can operate, the physical GPIOs must be placed into known states.

The button inputs are configured using pull-ups:

```c
GPIO_Input_PU(BUTTON_PORT, BUTTON_PIN);
```

and:

```c
GPIO_Input_PU(
    MODE_BUTTON_PORT,
    MODE_BUTTON_PIN
);
```

This gives the inputs a defined idle state instead of leaving them floating. 

The principle is:

```text
Floating input
     ↓
Unpredictable logic
     ↓
Possible false trigger
```

versus:

```text
Pull-up input
     ↓
Defined HIGH idle state
     ↓
Button pulls input LOW
     ↓
Predictable detection
```

---

# 4. Safety Layer 2 — Button Debouncing

A mechanical button does not transition cleanly between:

```text
HIGH → LOW
```

When pressed, its contacts can mechanically bounce.

A raw signal can therefore look like:

```text
HIGH
 ↓
LOW
 ↑
LOW
 ↑
LOW
 ↑
LOW
 ↓
LOW
```

If the firmware interpreted every transition as a valid press, one physical press could generate multiple QuickShifter events.

That would be unacceptable.

---

# 5. Software Debounce State Machine

The button driver therefore uses a state machine:

```text
BUTTON_STATE_RELEASED
        │
        ▼
BUTTON_STATE_DEBOUNCE_PRESS
        │
        ▼
BUTTON_STATE_PRESSED
        │
        ▼
BUTTON_STATE_DEBOUNCE_RELEASE
        │
        ▼
BUTTON_STATE_RELEASED
```

The same principle is implemented for the mode-selection button. 

When a press is first detected, the firmware does **not immediately accept it**.

Instead:

```text
Button goes LOW
      ↓
Start debounce timer
      ↓
Wait
      ↓
Read button again
      ↓
Still LOW?
      ↓
Valid press
```

This prevents short electrical/mechanical glitches from being treated as legitimate commands.

---

# 6. One-Shot Press Events

The shift button generates a press event:

```c
pressEvent = TRUE;
```

The application reads it using:

```c
Button_GetPress();
```

The event is then immediately cleared:

```c
pressEvent = FALSE;
```

Therefore a single valid physical press produces a **single logical event**. 

Conceptually:

```text
Physical press
      ↓
Debounce
      ↓
Valid press
      ↓
ONE event
      ↓
QuickShifter
```

rather than:

```text
Physical press
      ↓
multiple electrical transitions
      ↓
multiple relay triggers
```

---

# 7. Safety Layer 3 — QuickShifter State Machine

The QuickShifter itself is not implemented as a collection of unrelated `if` statements.

It uses a state machine.

The states are:

```text
IDLE
CUT_ACTIVE
COOLDOWN
WAIT_RELEASE
```

and the later robustness work also introduced a:

```text
FAULT
```

state.

The normal flow is:

```text
             Button press
                  │
                  ▼
               IDLE
                  │
                  ▼
            CUT_ACTIVE
                  │
            timer expires
                  │
                  ▼
             COOLDOWN
                  │
            timer expires
                  │
                  ▼
           WAIT_RELEASE
                  │
             button released
                  │
                  ▼
                IDLE
```

The state machine is implemented in `QuickShifter_Task()`. 

---

# 8. Why the State Machine Improves Safety

Without a state machine, the firmware might accidentally allow:

```text
Button press
 ↓
Relay ON

Button still pressed
 ↓
Another trigger

Button still pressed
 ↓
Another trigger
```

The state machine explicitly separates these conditions.

For example:

```text
CUT_ACTIVE
```

does not look for another shift trigger.

Instead, it waits for the cut timer to expire.

Then:

```text
COOLDOWN
```

ignores additional shift requests.

Finally:

```text
WAIT_RELEASE
```

ensures the original button interaction has ended before returning to `IDLE`. 

---

# 9. Safety Layer 4 — Relay OFF During Initialization

The relay driver is initialized as part of:

```c
QuickShifter_Init();
```

The design explicitly treats relay initialization as a safety boundary.

The state machine then starts in:

```c
QS_STATE_IDLE
```

where:

```text
Relay = OFF
```

is the expected condition. 

Therefore the firmware does not begin with:

```text
Unknown state
+
Unknown relay state
```

Instead:

```text
Startup
 ↓
Relay initialization
 ↓
Known OFF state
 ↓
IDLE
```

---

# 10. Safety Layer 5 — Selected Cut-Time Control

The QuickShifter does not use an arbitrary delay.

The selected mode determines the cut duration.

The system currently supports:

```text
Mode 1 → 40 ms
Mode 2 → 50 ms
Mode 3 → 60 ms
Mode 4 → 70 ms
Mode 5 → 80 ms
```

The active duration is obtained through:

```c
Mode_GetCutTime();
```

and passed to the software timer:

```c
SoftwareTimer_Start(
    &relayTimer,
    Mode_GetCutTime()
);
```

This separates:

```text
Mode selection
```

from:

```text
Timing execution
```

which makes the firmware easier to reason about and validate.

---

# 11. Safety Layer 6 — Hardware/System Timer Foundation

The QuickShifter does not use random software delay loops such as:

```c
delay_ms(70);
```

for its control logic.

Instead, timing is based on the timer/software-timer architecture.

This is important because the firmware needs to continue executing other tasks while timing is taking place.

Conceptually:

```text
System timer
     ↓
Time base
     ↓
Software timer
     ↓
40–80 ms cut timing
```

This allows:

```text
Button_Update()
ModeButton_Update()
QuickShifter_Task()
Watchdog_Refresh()
```

to continue operating within the main loop instead of blocking the CPU for the entire cut duration. The main loop explicitly calls these tasks continuously. 

---

# 12. Safety Layer 7 — Relay Cut Timer

When a valid shift is detected:

```c
Relay_On();
```

and immediately:

```c
SoftwareTimer_Start(
    &relayTimer,
    Mode_GetCutTime()
);
```

The relay therefore has a defined software-controlled ON duration. 

The sequence is:

```text
Valid shift
   ↓
Relay ON
   ↓
Start cut timer
   ↓
Timer running
   ↓
Timer expires
   ↓
Relay OFF
```

This is the primary functional timing protection.

---

# 13. Safety Layer 8 — Explicit Relay OFF

The relay is not simply allowed to remain in whatever state it was last commanded.

When the cut timer expires:

```c
Relay_Off();
```

is explicitly called. 

The same principle is used when the state machine reaches an invalid/default state:

```c
Relay_Off();
currentState = QS_STATE_IDLE;
```

This is a very important embedded-systems principle:

> **A fault path should drive the actuator toward a safe state.**

For this project:

```text
Safe actuator state = Relay OFF
```

---

# 14. Safety Layer 9 — Cooldown Protection

After the relay is turned OFF, the firmware does not immediately return to normal triggering.

Instead:

```c
SoftwareTimer_Start(
    &cooldownTimer,
    100
);
```

and enters:

```text
QS_STATE_COOLDOWN
```

The sequence is:

```text
Relay OFF
   ↓
100 ms cooldown
   ↓
WAIT_RELEASE
   ↓
Button release
   ↓
IDLE
```

This prevents rapid retriggering.

---

# 15. Why Cooldown Exists

Imagine a button is pressed and released very quickly.

Without cooldown:

```text
Press
 ↓
Relay ON
 ↓
Relay OFF
 ↓
Immediately ready again
 ↓
Electrical/mechanical transient
 ↓
Possible second trigger
```

With cooldown:

```text
Press
 ↓
Relay ON
 ↓
Relay OFF
 ↓
100 ms lockout
 ↓
WAIT_RELEASE
 ↓
Ready
```

So the system gets a controlled recovery period after each cut.

---

# 16. Safety Layer 10 — Wait for Button Release

The firmware also has a dedicated:

```text
QS_STATE_WAIT_RELEASE
```

state.

The system waits until:

```c
Button_IsPressed() == FALSE
```

before returning to:

```text
QS_STATE_IDLE
```

This prevents a long button press from becoming:

```text
one press
→ many cuts
```

Instead:

```text
Press
 ↓
One cut
 ↓
Cooldown
 ↓
Wait until release
 ↓
Ready for next press
```

---

# 17. Safety Layer 11 — Invalid State Recovery

The state machine contains a default path.

If `currentState` somehow contains a value that does not correspond to a valid state, the firmware executes:

```c
Relay_Off();

currentState = QS_STATE_IDLE;
```

Therefore:

```text
Invalid state
     ↓
Relay OFF
     ↓
Return to known state
     ↓
IDLE
```

This is much safer than allowing undefined state behavior to continue.

---

# 18. Safety Layer 12 — Mode Validation

Mode selection is also protected.

The EEPROM layer validates that the stored mode is within the permitted range before accepting it. The current EEPROM implementation checks against:

```c
EEPROM_MIN_MODE
EEPROM_MAX_MODE
```

and falls back to Mode 1 when the stored mode is invalid. 

Therefore corrupted data cannot directly result in an arbitrary mode.

Conceptually:

```text
EEPROM mode
     ↓
Range check
     ↓
1–5 ?
 ┌───┴───┐
YES      NO
 │        │
 ▼        ▼
Accept   Mode 1
```

---

# 19. Safety Layer 13 — EEPROM Magic Number

EEPROM configuration contains a magic value.

The current EEPROM header defines:

```c
#define EEPROM_MAGIC_ADDRESS      0x4000
#define EEPROM_MODE_ADDRESS       0x4001
#define EEPROM_CHECKSUM_ADDRESS   0x4002

#define EEPROM_MAGIC              0xA5
```

The magic value answers:

> “Does this EEPROM area contain configuration data in the format this firmware expects?”

So:

```text
0xA5
```

acts as an identification marker.

---

# 20. Safety Layer 14 — EEPROM Checksum

The stored mode is not trusted by itself.

The firmware calculates:

```text
checksum = MAGIC ^ MODE ^ 0x5A
```

and compares the calculated value against the stored checksum. 

The validation process is:

```text
Read EEPROM
    │
    ├── Magic
    ├── Mode
    └── Checksum
          │
          ▼
Calculate expected checksum
          │
          ▼
Compare
      ┌───┴───┐
    MATCH   MISMATCH
      │         │
      ▼         ▼
   Accept    Default Mode
```

This protects against simple EEPROM data corruption.

---

# 21. Safety Layer 15 — EEPROM Write Verification

Saving a mode does not simply mean:

```text
Write → assume success
```

The firmware writes:

```text
MODE
CHECKSUM
MAGIC
```

and then reads the values back for verification. 

The verification checks:

```c
readBackMagic == EEPROM_MAGIC
```

```c
readBackMode == mode
```

```c
readBackChecksum == checksum
```

Only when all three match is:

```text
SAVE SUCCESS
```

reported.

This provides a basic write-integrity check.

---

# 22. Why MAGIC Is Written Last

The EEPROM save sequence is structured as:

```text
Write MODE
     ↓
Write CHECKSUM
     ↓
Write MAGIC
```

The idea is that the configuration marker is written after the configuration contents.

Therefore, if a write sequence is interrupted before completion, the firmware should not blindly treat partially updated data as a valid configuration.

The final verification then confirms that the complete configuration exists.

---

# 23. EEPROM Legacy Configuration Handling

The firmware also contains compatibility handling for the previous EEPROM representation.

The legacy format used:

```text
0 → Mode 1
1 → Mode 2
2 → Mode 3
3 → Mode 4
4 → Mode 5
```

The current format uses the user-visible mode numbering directly.

The EEPROM loader detects the legacy magic value, validates the legacy checksum, converts the old representation, and saves the converted configuration using the new format. 

This prevents an EEPROM format change from automatically making existing stored configuration unusable.

---

# 24. Safety Layer 16 — EEPROM + Watchdog Interaction

Adding the watchdog exposed an important firmware-level problem.

The EEPROM save operation contains blocking operations.

The UART debug system is also blocking.

The initial architecture was:

```text
Main loop
   ↓
Watchdog refresh
   ↓
EEPROM_SaveMode()
   ↓
Large amount of UART output
   ↓
Main loop temporarily not reached
   ↓
Watchdog timeout
   ↓
MCU reset
```

This initially made it look like EEPROM was broken.

However, disabling the watchdog proved that EEPROM was functioning correctly.

---

# 25. Watchdog-Aware EEPROM

The EEPROM driver was therefore modified so that blocking EEPROM operations service the watchdog.

For example:

```c
while((FLASH_IAPSR & FLASH_IAPSR_EOP) == 0)
{
    Watchdog_Refresh();
}
```

Watchdog refreshes were also added between EEPROM programming operations and after verification. 

The result is:

```text
EEPROM operation
      │
      ├── Write
      ├── Watchdog refresh
      ├── Write
      ├── Watchdog refresh
      ├── Write
      └── Verify
```

---

# 26. Safety Layer 17 — Watchdog-Aware Debug UART

The larger issue was the blocking UART debug output.

The debug system was changed so that individual UART transmissions can service the watchdog.

The architecture became:

```text
Debug_Log()
     ↓
Debug_SendChar()
     ↓
UART_SendChar()
     ↓
Watchdog_Refresh()
```

The watchdog therefore remains alive during legitimate lengthy debug output.

This was particularly important because the UART implementation waits for the transmitter to become ready before sending each character. 

---

# 27. Why We Did Not Simply Disable the Watchdog During EEPROM

A tempting solution would have been:

```text
Watchdog OFF
     ↓
EEPROM operation
     ↓
Watchdog ON
```

We deliberately did not choose that architecture.

Why?

Because if the firmware becomes stuck during that EEPROM operation, the watchdog would not be available.

Instead, the system now allows the watchdog to continue operating during legitimate blocking activity.

That preserves the fundamental safety principle:

```text
Legitimate operation
       ↓
Watchdog serviced

Genuine firmware lock-up
       ↓
No servicing
       ↓
Watchdog RESET
```

---

# 28. Safety Layer 18 — Independent Watchdog

The final major safety layer is the STM8 Independent Watchdog (IWDG).

The application provides:

```c
Watchdog_Init();
```

and:

```c
Watchdog_Refresh();
```

The normal main loop refreshes the watchdog continuously. 

Conceptually:

```text
Main loop
   │
   ├── Button_Update()
   ├── ModeButton_Update()
   ├── QuickShifter_Task()
   │
   └── Watchdog_Refresh()
           │
           ▼
       IWDG alive
```

---

# 29. What the Watchdog Protects Against

The watchdog is not primarily protecting against:

```text
Button bounce
```

or:

```text
Relay timing
```

Those already have dedicated protection.

The watchdog protects against **firmware execution failure**.

Examples include:

* Main loop getting stuck
* Unexpected infinite loop
* Software deadlock
* Unexpected execution path
* Firmware becoming unresponsive

The watchdog provides a hardware recovery mechanism.

---

# 30. Watchdog Fault-Injection Test

The watchdog was not considered complete merely because the code compiled.

A deliberate fault-injection test was performed.

The normal:

```c
Watchdog_Refresh();
```

was intentionally disabled.

The firmware then executed normally but never refreshed the watchdog.

The expected sequence was:

```text
Watchdog started
      ↓
No refresh
      ↓
Watchdog counter continues
      ↓
Timeout
      ↓
STM8 reset
      ↓
main() starts again
```

This behavior was actually observed on the hardware.

The MCU repeatedly restarted at approximately the watchdog timeout interval.

Therefore the IWDG reset mechanism has been **experimentally verified**, not merely assumed.

---

# 31. Watchdog Option-Byte Verification

The STM8 option bytes were checked using ST Visual Programmer.

The configuration was confirmed as:

```text
IWDG_HW
Independent Watchdog activated by Software
```

Therefore the watchdog is intentionally started by firmware rather than automatically at power-on.

This matches the software architecture.

---

# 32. Complete Safety Architecture

At this point the QuickShifter has several independent safety mechanisms.

```text
                         INPUT
                           │
                           ▼
                    GPIO + Pull-up
                           │
                           ▼
                     Debounce FSM
                           │
                           ▼
                    One-shot Event
                           │
                           ▼
                    QuickShifter FSM
                           │
              ┌────────────┴────────────┐
              │                         │
              ▼                         ▼
         Cut Timer                 State Safety
              │                         │
              ▼                         ▼
         Relay OFF                Invalid → OFF
              │
              ▼
          Cooldown
              │
              ▼
        Wait Release
              │
              ▼
             IDLE

MODE CONFIGURATION PATH
────────────────────────

Mode Button
     │
     ▼
Debounce
     │
     ▼
Mode Change
     │
     ▼
Range Validation
     │
     ▼
EEPROM
     │
     ├── Magic validation
     ├── Mode validation
     ├── Checksum validation
     └── Read-back verification

FIRMWARE SAFETY PATH
─────────────────────

Main Loop
    │
    ▼
Watchdog Refresh
    │
    ▼
IWDG

If firmware stops:
    │
    ▼
No refresh
    │
    ▼
IWDG timeout
    │
    ▼
MCU RESET
```

---

# 33. Safety Layers Summary

| Layer | Protection | Failure Prevented |
| ----- | --- | --- |
| 1 | GPIO pull-up/input configuration | Floating inputs |
| 2 | Button debounce | Mechanical/electrical bounce |
| 3 | One-shot button events | Multiple triggers from one press |
| 4 | QuickShifter state machine | Invalid sequencing |
| 5 | Relay initialization | Unknown startup relay state |
| 6 | Mode-based timer | Undefined cut duration |
| 7 | Cut timer | Excessive normal relay activation |
| 8 | Explicit `Relay_Off()` | Relay remaining active after cut |
| 9 | Cooldown | Immediate retriggering |
| 10 | Wait-release state | Long press causing repeated cuts |
| 11 | Invalid-state recovery | Undefined FSM behavior |
| 12 | Mode range validation | Invalid configuration |
| 13 | EEPROM magic | Unknown/uninitialized data |
| 14 | EEPROM checksum | Corrupted configuration |
| 15 | EEPROM read-back | Failed EEPROM write |
| 16 | EEPROM watchdog servicing | Legitimate EEPROM blocking causing reset |
| 17 | Watchdog-aware UART | Debug logging starving watchdog |
| 18 | Independent watchdog | Firmware lock-up |
| 19 | Watchdog fault injection | Unverified watchdog assumptions |

---

# 34. Failure → Protection Mapping

A useful way to understand the design is to start from the failure.

### Button bounces

```text
Button bounce
     ↓
Debounce FSM
     ↓
One valid event
```

### Button held

```text
Button held
     ↓
CUT_ACTIVE
     ↓
COOLDOWN
     ↓
WAIT_RELEASE
     ↓
No additional cut
```

### Normal cut timer expires

```text
Timer expires
     ↓
Relay_Off()
```

### State corruption

```text
Invalid state
     ↓
Relay_Off()
     ↓
IDLE
```

### EEPROM corruption

```text
Bad magic/checksum/mode
     ↓
Reject configuration
     ↓
Default Mode 1
```

### EEPROM write failure

```text
Write
 ↓
Read-back
 ↓
Mismatch
 ↓
SAVE FAILED
```

### Long EEPROM/UART operation

```text
Blocking operation
     ↓
Watchdog serviced
     ↓
No false reset
```

### Firmware lock-up

```text
Firmware stops
     ↓
No watchdog refresh
     ↓
IWDG timeout
     ↓
MCU RESET
```

---

# 35. What Has Actually Been Tested

The important distinction is between **implemented** and **verified**.

### Verified on hardware

* Button operation
* Mode switching
* Mode persistence
* EEPROM read/write
* EEPROM checksum validation
* EEPROM read-back verification
* Relay operation
* QuickShifter state machine operation
* Selected cut modes
* Watchdog activation
* Watchdog timeout
* Automatic MCU reset
* Watchdog survival during EEPROM/debug operation

The watchdog fault-injection test was especially important because it demonstrated that deliberately stopping watchdog servicing causes the STM8 to restart.

---

# 36. What Is NOT Yet Completed

The current safety architecture is strong, but it is **not yet the final production safety architecture**.

The following are intentionally left for later:

```text
Reset-cause detection
        ↓
Persistent watchdog fault logging
        ↓
Startup fault diagnostics
        ↓
More advanced watchdog health monitoring
        ↓
Production fault recovery strategy
```

We have specifically postponed reset-cause reporting for a later phase.

So we should **not document it as implemented yet**.

---

# 37. Current Safety Philosophy

The QuickShifter now follows three important principles:

### Principle 1 — Fail Safe

Whenever the firmware detects an invalid state:

```text
RELAY OFF
```

### Principle 2 — Validate Before Trusting

External/user-controlled data is not blindly trusted.

```text
Button → Debounce
Mode → Range check
EEPROM → Magic + checksum + range
EEPROM write → Read-back verification
```

### Principle 3 — Recover From Firmware Failure

If the firmware itself stops executing:

```text
No watchdog refresh
        ↓
IWDG timeout
        ↓
MCU reset
```

---

# 38. Final Architecture

The QuickShifter firmware has evolved from a basic relay controller into a layered embedded control system:

```text
                         ┌─────────────────────┐
                         │     QUICKSHIFTER     │
                         └──────────┬──────────┘
                                    │
             ┌──────────────────────┼──────────────────────┐
             │                      │                      │
             ▼                      ▼                      ▼
       INPUT SAFETY           CONTROL SAFETY          DATA SAFETY
             │                      │                      │
       ┌─────┴─────┐          ┌─────┴─────┐         ┌─────┴─────┐
       │           │          │           │         │           │
    Debounce    Events     Cut Timer   Cooldown   EEPROM     Checksum
       │           │          │           │         │           │
       └─────┬─────┘          └─────┬─────┘         └─────┬─────┘
             │                      │                      │
             └──────────────────────┼──────────────────────┘
                                    │
                                    ▼
                            STATE MACHINE
                                    │
                             ┌──────┴──────┐
                             │             │
                             ▼             ▼
                         Normal         Invalid
                             │             │
                             ▼             ▼
                       Relay control   Relay OFF
                                   
                                    │
                                    ▼
                           FIRMWARE SAFETY
                                    │
                                    ▼
                               IWDG
                                    │
                     ┌──────────────┴──────────────┐
                     │                             │
                Refreshing                    No refresh
                     │                             │
                     ▼                             ▼
               Keep running                  MCU RESET
```

---

# 39. Conclusion

The safety work completed so far is not a single feature. It is a collection of independent protections built around the most important requirement of the QuickShifter:

> **The relay must never remain active because of an unexpected firmware condition.**

The firmware therefore uses:

* debounced inputs,
* one-shot button events,
* a deterministic state machine,
* controlled cut timing,
* cooldown protection,
* release detection,
* explicit relay shutdown,
* invalid-state recovery,
* EEPROM validation,
* checksum protection,
* EEPROM write verification,
* watchdog-aware blocking operations,
* and an independently verified hardware watchdog.

The most significant validation performed in this phase was the deliberate watchdog fault injection.

The firmware was intentionally prevented from refreshing the watchdog, and the STM8S003F3 was observed to automatically reset.

This establishes a layered safety architecture:

```text
                USER INPUT
                    │
                    ▼
               VALIDATION
                    │
                    ▼
             STATE MACHINE
                    │
                    ▼
              TIMED RELAY
                    │
                    ▼
             SAFE SHUTDOWN
                    │
                    ▼
             FIRMWARE WATCHDOG
                    │
                    ▼
              MCU RECOVERY
```

This forms the current **safety foundation of the QuickShifter firmware**.

---

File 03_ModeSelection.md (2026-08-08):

# QuickShifter Firmware – Development Log Part 3
## UART Debugging, Mode Selection & Configurable Shift Timing

---

## 1. Overview

In this development stage, the QuickShifter firmware was extended with:

- UART-based debugging
- A dedicated debug abstraction layer
- Temporary USB-to-UART debugging using an ESP8266 NodeMCU board
- Serial monitoring through the onboard CP210x USB-UART bridge
- A second push button for mode selection
- Five configurable QuickShifter operating modes
- Mode-dependent shift cut timing
- Separation between mode selection and timer execution
- Debug output for monitoring the selected operating mode

The objective was to make the firmware easier to test and tune during development while keeping the debugging functionality removable from the final production firmware.

---

# 2. Development Debugging Architecture

The debugging architecture was designed so that the application code does not directly access UART registers.

The architecture is:

```text
QuickShifter Application
          ¦
          ?
       debug.c
       debug.h
          ¦
          ?
        uart.c
        uart.h
          ¦
          ?
      STM8 UART1
          ¦
          ?
      PD5 / TX
          ¦
          ?
 ESP8266 NodeMCU
   CP210x USB-UART
          ¦
          ?
         USB
          ¦
          ?
         PC
          ¦
          ?
      CoolTerm
````

This provides a clean separation between:

* Application logic
* Debugging functionality
* UART hardware implementation

---

# 3. UART Implementation

A dedicated UART driver was created:

```text
uart.c
uart.h
```

The driver provides:

```c
void UART_Init(void);
void UART_SendChar(char c);
void UART_SendString(const char *str);
```

The application does not directly manipulate UART registers.

Instead, it uses:

```c
Debug_Log("message");
```

which internally uses the UART driver.

---

# 4. STM8 UART Configuration

The STM8S003F3 UART1 peripheral is used for debugging.

The transmit pin is:

```text
PD5 ? UART1_TX
```

The current debug configuration is:

```text
Baud Rate : 9600
Data      : 8 bits
Parity    : None
Stop      : 1
```

Therefore:

```text
9600 8-N-1
```

The UART baud-rate configuration used for a 16 MHz system clock is:

```c
UART1_BRR1 = 0x68;
UART1_BRR2 = 0x02;
```

The UART driver configures PD5 as:

```text
Output
Push-Pull
Fast Mode
```

and enables the UART transmitter.

---

# 5. UART Debug Interface

A separate debug abstraction layer was created:

```text
debug.c
debug.h
```

The main functions are:

```c
void Debug_Init(void);

void Debug_Log(const char *message);

void Debug_LogState(uint8_t state);

void Debug_LogShift(uint16_t shift_time);

void Debug_LogMode(uint8_t mode, uint16_t cut_time);
```

The purpose of this layer is to prevent application code from becoming dependent on UART hardware.

For example, the QuickShifter firmware can simply call:

```c
Debug_Log("SHIFT DETECTED\r\n");
```

instead of directly accessing:

```c
UART1_DR
UART1_SR
UART1_BRR1
UART1_BRR2
```

---

# 6. Debug Enable / Disable

Debugging is controlled using:

```c
#define DEBUG_UART_ENABLED
```

When debugging is enabled:

```c
#define DEBUG_UART_ENABLED 1
```

the debug functions transmit data through UART.

For production:

```c
#define DEBUG_UART_ENABLED 0
```

the debug functions become empty stubs.

This allows the same application code to remain in the project without requiring the production hardware to contain a USB-UART interface.

The intended architecture is:

```text
Development:

QuickShifter
     ¦
     ?
   Debug
     ¦
     ?
   UART
     ¦
     ?
 USB-UART
     ¦
     ?
    PC
```

Production:

```text
QuickShifter
     ¦
     ?
   Debug
     ¦
     ?
   Disabled
```

---

# 7. Temporary ESP8266 Debugging Interface

An ESP8266 NodeMCU development board was used as a temporary USB-to-UART interface.

The NodeMCU board contains a CP210x USB-UART bridge.

The ESP8266 itself is not being used as the communication processor in this configuration.

The USB-UART bridge is being used to convert:

```text
STM8 UART
    ?
TTL UART
    ?
USB
```

for monitoring on the PC.

---

# 8. Final Working UART Connection

The following connection was successfully tested:

```text
STM8S003F3                 NodeMCU

PD5 / UART1_TX ----------- TX pin

GND ---------------------- GND
```

The NodeMCU was connected to the PC through USB.

The NodeMCU `EN` pin was held LOW during the USB-UART-only testing configuration:

```text
EN ? GND
```

The STM8 RX pin was not required for the current debugging system because communication is currently one-way:

```text
STM8 ? PC
```

Therefore:

```text
PD6 / UART1_RX
```

is currently unused.

---

# 9. Important NodeMCU Pin Discovery

During testing, an important pin-mapping issue was discovered.

Initially the STM8 UART TX was connected to the NodeMCU pin labelled:

```text
RX
```

No data was received.

A UART loopback test was performed on the NodeMCU:

```text
NodeMCU TX ? NodeMCU RX
```

The loopback successfully demonstrated that the CP210x USB-UART bridge was functional.

For the NodeMCU board being used as a USB-UART bridge, the working STM8 connection was found to be:

```text
STM8 PD5 / TX ? NodeMCU TX pin
```

This allowed the signal to reach the CP210x RX input and then the PC.

The final tested connection is therefore:

```text
STM8 TX
   ¦
   ?
NodeMCU TX-labelled pin
   ¦
   ?
CP210x RX
   ¦
   ?
USB
   ¦
   ?
PC
```

---

# 10. Serial Monitor Testing

CoolTerm was used as the serial monitor.

The final working configuration was:

```text
COM Port : COM10
Baud     : 9600
Data     : 8
Parity   : None
Stop     : 1
Local Echo : OFF
```

The STM8 successfully transmitted:

```text
================================
 QuickShifter Debug Console
================================
STM8 UART TEST
QuickShifter Debug Started
```

This confirmed that the complete communication chain was operational:

```text
STM8S003F3
     ?
UART1
     ?
PD5
     ?
NodeMCU / CP210x
     ?
USB
     ?
COM10
     ?
CoolTerm
```

---

# 11. Initial UART Test

Before adding application-level debugging, a simple test message was added to `main.c`:

```c
Debug_Init();

Debug_Log("STM8 UART TEST\r\n");
Debug_Log("QuickShifter Debug Started\r\n");
```

This was used to verify the UART hardware and software independently from the QuickShifter state machine.

Once the messages were successfully received, UART debugging was considered operational.

---

# 12. Why UART Debugging Is Event-Based

The QuickShifter contains timing-critical operations.

The relay cut time is in the range of tens of milliseconds.

Because UART transmission is relatively slow, excessive debug messages can interfere with firmware timing.

Therefore, debugging should be performed on significant events rather than continuously inside the main loop.

### Recommended:

```text
SHIFT DETECTED
RELAY ON
RELAY OFF
STATE CHANGE
MODE CHANGE
```

### Avoid:

```text
STATE = IDLE
STATE = IDLE
STATE = IDLE
STATE = IDLE
...
```

The debug system is therefore intended primarily for event-based logging.

---

# 13. Five Operating Modes

A five-mode system was introduced to make the QuickShifter cut time configurable.

The current modes are:

| Mode | Cut Time |
| --- | --- |
| Mode 1 | 40 ms |
| Mode 2 | 50 ms |
| Mode 3 | 60 ms |
| Mode 4 | 70 ms |
| Mode 5 | 80 ms |

The sequence is:

```text
Mode 1
  ?
Mode 2
  ?
Mode 3
  ?
Mode 4
  ?
Mode 5
  ?
Mode 1
  ?
...
```

---

# 14. Mode Manager

The mode logic is separated into:

```text
mode.c
mode.h
```

The mode manager is responsible for:

* Maintaining the current mode
* Switching to the next mode
* Returning the current mode
* Returning the selected cut time

The mode enumeration is:

```c
typedef enum
{
    QS_MODE_1 = 0,
    QS_MODE_2,
    QS_MODE_3,
    QS_MODE_4,
    QS_MODE_5

} QuickShifterMode_t;
```

---

# 15. Mode Timing Table

The timing values are stored in a constant array:

```c
static const uint16_t cutTimes[5] =
{
    40,
    50,
    60,
    70,
    80
};
```

The relationship is:

```text
Array Index      Cut Time

     0    ------- 40 ms
     1    ------- 50 ms
     2    ------- 60 ms
     3    ------- 70 ms
     4    ------- 80 ms
```

The current mode variable contains the array index.

For example:

```text
currentMode = 0
```

means:

```text
Mode 1
Cut = 40 ms
```

while:

```text
currentMode = 2
```

means:

```text
Mode 3
Cut = 60 ms
```

---

# 16. Mode Selection Logic

The mode button calls:

```c
Mode_Next();
```

The logic is:

```c
void Mode_Next(void)
{
    currentMode++;

    if(currentMode >= MODE_COUNT)
    {
        currentMode = QS_MODE_1;
    }
}
```

Therefore:

```text
0 ? 1 ? 2 ? 3 ? 4 ? 0
```

The wrap-around allows the user to continuously cycle through the five modes.

---

# 17. Getting the Selected Cut Time

The selected timing value is obtained using:

```c
uint16_t Mode_GetCutTime(void)
{
    return cutTimes[currentMode];
}
```

For example:

```text
currentMode = 0
        ?
cutTimes[0]
        ?
40 ms
```

or:

```text
currentMode = 3
        ?
cutTimes[3]
        ?
70 ms
```

---

# 18. Mode Button

Instead of creating a separate source file for the mode button, the existing:

```text
button.c
button.h
```

module is being extended.

This avoids duplicating the existing debounce implementation.

The button module now conceptually contains:

```text
button.c
¦
+-- Shift Button
¦   +-- Button_Init()
¦   +-- Button_Update()
¦   +-- Button_GetPress()
¦
+-- Mode Button
    +-- ModeButton_Init()
    +-- ModeButton_Update()
    +-- ModeButton_GetPress()
```

This keeps all physical push-button handling in one module.

---

# 19. Button GPIO Allocation

The current GPIO allocation is:

```text
PD2 ? Relay
PD3 ? Shift Button
PD4 ? Mode Button
PD5 ? UART1 TX
PD6 ? UART1 RX (currently unused)
```

The new mode button is connected as:

```text
PD4 ------- Push Button ------- GND
```

The internal pull-up resistor is used.

Therefore:

```text
Button Released ? PD4 = HIGH

Button Pressed  ? PD4 = LOW
```

The same debounce approach used by the existing shift button is used for the mode button.

---

# 20. Mode Button Debouncing

The mode button uses the existing software timer infrastructure for debouncing.

The debounce period is:

```c
#define BUTTON_DEBOUNCE_TIME 20
```

The button state machine follows:

```text
RELEASED
    ¦
    ¦ Button pressed
    ?
DEBOUNCE_PRESS
    ¦
    ¦ 20 ms stable
    ?
PRESSED
    ¦
    ¦ Button released
    ?
DEBOUNCE_RELEASE
    ¦
    ¦ 20 ms stable
    ?
RELEASED
```

A single valid button press generates one event:

```c
ModeButton_GetPress()
```

This prevents switch bounce from changing multiple modes from one physical press.

---

# 21. Mode Selection Flow

The complete mode selection process is:

```text
User presses MODE button
          ¦
          ?
        PD4
          ¦
          ?
ModeButton_Update()
          ¦
          ?
Debounce
          ¦
          ?
ModeButton_GetPress()
          ¦
          ?
      Mode_Next()
          ¦
          ?
 currentMode changes
          ¦
          ?
Mode_GetCutTime()
          ¦
          ?
Selected cut time
```

---

# 22. Example Mode Sequence

Starting from the default:

```text
Mode 1
40 ms
```

Pressing the mode button once:

```text
Mode 2
50 ms
```

Second press:

```text
Mode 3
60 ms
```

Third press:

```text
Mode 4
70 ms
```

Fourth press:

```text
Mode 5
80 ms
```

Fifth press:

```text
Mode 1
40 ms
```

---

# 23. Relationship Between Mode and Timer

An important design concept is that the **Mode Manager does not measure time**.

The Mode Manager only determines the requested duration:

```text
Mode Manager
     ¦
     ?
40 / 50 / 60 / 70 / 80 ms
```

The existing software timer is responsible for measuring the elapsed time.

The intended flow is:

```text
Mode Manager
     ¦
     ¦ Selected duration
     ?
QuickShifter
     ¦
     ?
SoftwareTimer_Start()
     ¦
     ?
Hardware Timer Tick
     ¦
     ?
Elapsed Time
     ¦
     ?
SoftwareTimer_Expired()
     ¦
     ?
Relay OFF
```

Therefore, the five modes do not create five different hardware timers.

The same timer system is reused with a different target duration.

---

# 24. Example: Mode 3

Suppose the user selects:

```text
Mode 3
```

The mode manager returns:

```text
60 ms
```

The QuickShifter will eventually use:

```c
SoftwareTimer_Start(&relayTimer,
                    Mode_GetCutTime());
```

which is equivalent to:

```c
SoftwareTimer_Start(&relayTimer, 60);
```

The timer then measures the elapsed time until the requested duration has passed.

Conceptually:

```text
Relay ON
   ¦
   +-- 1 ms
   +-- 2 ms
   +-- 3 ms
   ¦
   ¦   ...
   ¦
   +-- 59 ms
   +-- 60 ms
          ¦
          ?
       Timer Expired
          ¦
          ?
       Relay OFF
```

---

# 25. Important Current Status

At this stage, the following components have been implemented:

```text
[?] UART driver
[?] UART1 TX on PD5
[?] 9600 baud communication
[?] Debug abstraction layer
[?] Debug enable/disable mechanism
[?] ESP8266/CP210x USB-UART debugging
[?] CoolTerm serial monitoring
[?] Second mode button
[?] Mode button debounce
[?] Five operating modes
[?] Mode cycling
[?] Mode-dependent timing table
[?] UART mode reporting
```

The next firmware integration step is to ensure the actual QuickShifter relay timer uses:

```c
Mode_GetCutTime()
```

instead of the previous fixed shift-time value.

---

# 26. Current Firmware Architecture

The project is now structured conceptually as:

```text
                         MAIN
                          ¦
          +---------------+----------------+
          ¦               ¦                ¦
          ?               ?                ?
      Shift Button    Mode Button      Debug
          ¦               ¦                ¦
          ?               ?                ?
       button.c        button.c         debug.c
          ¦               ¦                ¦
          ¦               ?                ?
          ¦            mode.c           uart.c
          ¦               ¦                ¦
          ¦               ?                ?
          ¦          Cut Time           UART1
          ¦               ¦                ¦
          +---------------¦                ¦
                          ?                ¦
                    QuickShifter           ¦
                          ¦                ¦
                          ?                ¦
                   Software Timer          ¦
                          ¦                ¦
                          ?                ¦
                       Relay               ¦
                                           ¦
                                           ?
                                  NodeMCU / CP210x
                                           ¦
                                           ?
                                        CoolTerm
```

---

# 27. Development Hardware Configuration

Current development setup:

```text
STM8S003F3
¦
+-- PD2 ? Relay Module
¦
+-- PD3 ? Shift Button
¦
+-- PD4 ? Mode Button
¦
+-- PD5 ? UART TX
             ¦
             ?
        NodeMCU / CP210x
             ¦
             ?
            USB
             ¦
             ?
            PC
             ¦
             ?
          CoolTerm
```

The ESP8266 NodeMCU is being used only as a temporary debugging interface.

It is not part of the intended production QuickShifter architecture.

---

# 28. Production Consideration

The debug system is intentionally designed to be removable.

During development:

```text
STM8
 ¦
 +-- UART TX ? Debug Interface ? PC
```

During production:

```text
DEBUG_UART_ENABLED = 0
```

and the debug output is disabled.

The production PCB can optionally expose a small debug header containing:

```text
GND
TX
RX
```

This allows debugging hardware to be connected when required without permanently including the USB-UART converter in the final product.

---

# 29. Next Development Step

The next task is to integrate the mode timing directly into the QuickShifter state machine.

The current target is:

```c
SoftwareTimer_Start(
    &relayTimer,
    Mode_GetCutTime()
);
```

After this integration, the complete system will work as:

```text
                MODE BUTTON
                     ¦
                     ?
             Select Mode 1–5
                     ¦
                     ?
            Select 40–80 ms
                     ¦
                     ?
                SHIFT EVENT
                     ¦
                     ?
                RELAY ON
                     ¦
                     ?
              Software Timer
                     ¦
                     ?
            Selected time elapsed
                     ¦
                     ?
                RELAY OFF
```

The UART debugger will then be used to verify the complete sequence and selected timing during development.

````

### Current milestone

The most important thing we've achieved in this stage is that **the STM8 is now talking to your PC through UART successfully**, and we've built the firmware structure so that the new 5-mode system doesn't interfere with the existing QuickShifter state machine.

The next milestone should be **actual mode-dependent relay timing + UART output such as**:

```text
[MODE] 3 | CUT = 60 ms
[QS] SHIFT DETECTED
[QS] RELAY ON
[QS] RELAY OFF
[QS] CUT COMPLETE
````

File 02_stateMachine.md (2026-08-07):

# Quick Shifter Firmware Documentation

# Part 2 – Firmware Architecture & Non-Blocking System

## Overview

After validating the basic hardware (STM8S003F3, relay module, shift button, and GPIO operation), the firmware was redesigned to follow a modular and scalable architecture. The objective was to eliminate blocking delays and prepare the firmware for future features such as multiple shift modes, EEPROM storage, and safety mechanisms.

This phase focused on building the software foundation rather than adding new features.

---

# Objectives

The goals of this phase were:

* Replace blocking delays with timer-based execution.
* Generate an accurate 1 ms system tick.
* Develop reusable software timers.
* Design a finite state machine (FSM) for the quick shifter.
* Build a non-blocking button driver.
* Establish a scalable firmware architecture suitable for future expansion.

---

# System Clock Configuration

Initially, the STM8S003F3 runs from the internal High-Speed Internal (HSI) oscillator at **16 MHz** with a default clock divider of **8**, resulting in a CPU frequency of **2 MHz**.

To improve timer accuracy and overall performance, the firmware configures the clock divider to **1**, allowing the CPU to operate at the full **16 MHz**.

```c
CLK_CKDIVR = 0x00;
```

Result:

```
HSI Oscillator : 16 MHz
Clock Divider  : 1
CPU Frequency  : 16 MHz
```

Operating at 16 MHz enables precise timer calculations and provides sufficient processing time for future features.

---

# Hardware Timer (TIM4)

## Purpose

A hardware timer was required to create a reliable system time base.

TIM4 was selected because:

* Available on STM8S003F3
* Simple 8-bit timer
* Dedicated update interrupt
* Suitable for operating system style system ticks

---

## Timer Configuration

| Parameter | Value |
| --- | ---: |
| CPU Clock |  16 MHz |
| Prescaler | 128 |
| Timer Clock | 125 kHz |
| Auto Reload (ARR) | 124 |
| Interrupt Period  | 1 ms |

Calculation:

```
16 MHz / 128 = 125000 Hz

125000 / 125 = 1000 Hz

Interrupt Period = 1 ms
```

---

## Timer Driver

A dedicated timer driver was created.

### timer.h

Responsible for:

* Timer initialization
* Tick retrieval
* Delay function (for initialization only)
* ISR interface

### timer.c

Responsible for:

* TIM4 configuration
* System tick generation
* Tick management

The timer module hides all TIM4 hardware details from the application layer.

---

# System Tick

A global millisecond counter was introduced.

```c
volatile uint32_t system_tick;
```

Every TIM4 interrupt increments this variable.

```
TIM4 Interrupt

?

system_tick++
```

The system tick becomes the common time reference for the entire firmware.

---

# Timer API

The timer driver exposes the following interface:

```c
void Timer_Init(void);

uint32_t Timer_GetTick(void);

void Timer_Delay(uint32_t ms);

void Timer_TickISR(void);
```

`Timer_Delay()` is retained only for initialization and debugging. Application code should avoid using blocking delays.

---

# Interrupt Vector Integration

TIM4 Update/Overflow interrupt was connected to interrupt vector 23.

The ISR performs only two operations:

* Clear interrupt flag
* Update system tick

This follows the embedded software principle:

> Keep interrupt service routines as short as possible.

---

# Timer Verification

The timer was verified by toggling the relay output every 500 ms using the system tick.

```text
Timer_GetTick()

?

500 ms elapsed?

?

Toggle Output
```

Successful verification confirmed:

* Correct clock configuration
* Proper interrupt vector mapping
* Working TIM4 interrupt
* Accurate 1 ms system tick

---

# Software Timer Module

## Motivation

Using blocking delays prevents the CPU from executing other tasks.

Example:

```c
Timer_Delay(40);
```

During these 40 ms:

* Button cannot be read
* State machine cannot execute
* Safety logic stops
* Future features become impossible

Instead, software timers store:

* Start time
* Duration
* Active status

Example:

```c
SoftwareTimer_Start(&relayTimer,40);

if(SoftwareTimer_Expired(&relayTimer))
{
    ...
}
```

This allows multiple independent timers to operate simultaneously using the same hardware timer.

---

# Software Timer Structure

```c
typedef struct
{
    uint32_t start_time;
    uint32_t duration;
    uint8_t active;

} SoftwareTimer_t;
```

---

# Software Timer API

```c
void SoftwareTimer_Start();

void SoftwareTimer_Stop();

uint8_t SoftwareTimer_Expired();

uint8_t SoftwareTimer_IsRunning();
```

This module forms the timing backbone of the firmware.

---

# Quick Shifter State Machine

The original firmware executed sequentially.

```
Button

?

Relay ON

?

Delay

?

Relay OFF
```

This architecture was replaced by a finite state machine.

---

## State Diagram

```
                +----------------------+
                |        IDLE          |
                +----------+-----------+
                           |
                           | Shift Detected
                           |
                           ?
                +----------------------+
                |    CUT_ACTIVE        |
                +----------+-----------+
                           |
                           | Cut Time Expired
                           |
                           ?
                +----------------------+
                |     COOLDOWN         |
                +----------+-----------+
                           |
                           | Cooldown Complete
                           |
                           ?
                +----------------------+
                |   WAIT_RELEASE       |
                +----------+-----------+
                           |
                           | Button Released
                           |
                           ?
                        IDLE
```

---

## State Description

### IDLE

System waits for a valid shift input.

---

### CUT_ACTIVE

Relay activates, interrupting ignition.

A software timer measures the cut duration.

---

### COOLDOWN

After relay deactivation, the firmware ignores new requests for a fixed period.

This prevents repeated triggering caused by linkage vibration.

---

### WAIT_RELEASE

The firmware waits until the shift sensor is released.

This guarantees only one ignition cut per gear shift.

---

# Button Driver Redesign

The original button driver used:

```c
Timer_Delay(20);

while(button_pressed);
```

This caused:

* Blocking execution
* Ignition cut only after button release
* Poor scalability

The driver was redesigned into its own finite state machine.

---

## Button States

```
Released

?

Debounce Press

?

Pressed

?

Debounce Release

?

Released
```

The new driver:

* Debounces using software timers.
* Generates a single press event.
* Does not block execution.
* Detects the press immediately rather than waiting for release.

---

# Main Application Loop

The firmware now executes continuously without blocking.

```c
while(1)
{
    Button_Update();

    QuickShifter_Task();
}
```

Every module executes independently and cooperatively.

---

# Layered Firmware Architecture

```
                    main()

                      ¦

                      ?

            QuickShifter_Task()

                      ¦

      +-------------------------------+

      ?                               ?

 Button Driver                 Software Timer

      ¦                               ¦

      +-------------------------------+

                      ?

                 Timer Driver

                      ¦

                      ?

                 TIM4 Hardware
```

Each layer performs a single responsibility.

---

# Lessons Learned

During this development phase several important embedded software concepts were implemented:

* System clock configuration
* Hardware timer configuration
* Interrupt vector mapping
* Interrupt Service Routine design
* Millisecond system tick generation
* Software timer implementation
* Event-driven programming
* Finite State Machine design
* Layered firmware architecture
* Non-blocking embedded software design
* Modular driver development
* Separation of hardware and application layers

---

# Current Project Status

| Module | Status |
| --- | --- |
| Clock Driver | ? Complete |
| GPIO Driver | ? Complete |
| Relay Driver | ? Complete |
| Hardware Timer (TIM4) | ? Complete |
| Software Timer | ? Complete |
| Button Driver (FSM) | ? Complete |
| Quick Shifter State Machine | ? Complete |
| 5 Shift Modes | ? Next Phase |
| EEPROM Storage | ? Planned |
| Safety Features | ? Planned |

---

# Next Development Phase (Part 3)

The next phase of development will focus on product-level functionality:

* Implement five selectable ignition cut modes.
* Add mode selection button.
* Store the selected mode in internal EEPROM.
* Restore the saved mode on power-up.
* Add LED indication for the active mode.
* Implement startup self-test.
* Add relay timeout protection.
* Add shift sensor fault detection.
* Improve overall firmware robustness.

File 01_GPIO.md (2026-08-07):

# Phase 1 – GPIO, Button Interface, Relay Pulse & Timer Validation

## Project

Quick Shifter Firmware

Platform:
- STM8S003F3P6
- Cosmic Compiler
- ST Visual Develop (STVD)
- ST Visual Programmer (STVP)

---

# Objective

The objective of this phase was to build the hardware abstraction layer required
for the Quick Shifter firmware.

Instead of directly writing application logic, the firmware was divided into
independent modules to improve readability, scalability and maintainability.

The following features were implemented.

? GPIO Driver

? Button Driver

? Clock Configuration

? TIM4 Delay Driver

? Relay Pulse Generation

? QuickShifter Application Layer

---

# Hardware Used

Controller

STM8S003F3P6

Clock

Internal High Speed Oscillator (HSI)

Configured Frequency

16 MHz

Programming Interface

ST-Link V2

---

# Hardware Connections

## Button

PD3

Configuration

Input Pull-up

Circuit

PD3
 ¦
Push Button
 ¦
GND

Released

Logic HIGH

Pressed

Logic LOW

---

## Relay Module

PD2

Configuration

Push Pull Output

Connection

STM8 PD2 -------------- IN

5V --------------------- VCC

GND -------------------- GND

STM8 GND --------------- GND

The relay module already contains

• Driver Transistor

• Flyback Diode

• Status LED

No external MOSFET was used during this phase.

---

# Firmware Architecture

Application Layer

main.c

?

QuickShifter.c

?

Button Driver

Relay Driver

Timer Driver

GPIO Driver

?

STM8 Hardware Registers

This architecture keeps the application independent from hardware details.

---

# Project Structure

Include

common.h

config.h

stm8_hw.h

gpio.h

button.h

timer.h

clock.h

relay.h

quickshifter.h

Source

main.c

gpio.c

button.c

timer.c

clock.c

relay.c

quickshifter.c

---

# Module Description

## common.h

Contains

• Standard data types

uint8_t

uint16_t

uint32_t

• TRUE

• FALSE

Purpose

Provides common definitions used by every module.

---

## config.h

Contains project level configuration.

Example

Relay Pin

Button Pin

Future versions will also contain

Shift Time

Mode Selection

EEPROM Addresses

etc.

Changing a pin only requires modifying one file.

---

## stm8_hw.h

Contains STM8 register definitions.

Example

PD_ODR

PD_IDR

PD_DDR

PD_CR1

PD_CR2

TIM4 Registers

Clock Registers

Purpose

Separates hardware register addresses from application code.

---

## gpio.c

Purpose

Provides reusable GPIO functions.

Functions

GPIO_Output_PP()

GPIO_Input_PU()

GPIO_Set()

GPIO_Clear()

GPIO_Toggle()

GPIO_Read()

The application never directly accesses registers.

---

## button.c

Purpose

Handles button interface.

Features

Internal Pull-up

Software Debounce

Press Detection

Button Release Detection

The application simply calls

Button_GetPress()

---

## clock.c

Purpose

Configures the STM8 clock.

Default STM8 Frequency

2 MHz

Configured Frequency

16 MHz

Function

CLK_Init()

Reason

All timing calculations are based on 16 MHz.

---

## timer.c

Purpose

Provides accurate millisecond delays.

Peripheral Used

TIM4

Functions

TIM4_Init()

TIM4_Delay_ms()

Current Usage

Relay pulse generation

Button debounce

Future Usage

Shift timing

State machine timing

Timeout management

---

## relay.c

Purpose

Provides relay abstraction.

Functions

Relay_Init()

Relay_On()

Relay_Off()

Relay_Pulse()

The application never directly controls GPIO.

---

## quickshifter.c

Purpose

Contains application logic.

Current Logic

Button Press

?

Relay ON

?

40 ms Delay

?

Relay OFF

Future versions will include

Trigger Detection

Mode Selection

EEPROM

Engine Cut Timing

State Machine

---

# GPIO Configuration

## Relay Output

Pin

PD2

Mode

Output

Push Pull

Slow Mode

Interrupt

Disabled

Registers

DDR = 1

CR1 = 1

CR2 = 0

---

## Button Input

Pin

PD3

Mode

Input Pull-up

Interrupt

Disabled

Registers

DDR = 0

CR1 = 1

CR2 = 0

Released

HIGH

Pressed

LOW

---

# Button Debouncing

Mechanical push buttons do not produce a clean transition.

Instead they generate multiple transitions within a few milliseconds.

Without debouncing

HIGH

LOW

HIGH

LOW

HIGH

LOW

The controller interprets multiple presses.

Solution

After detecting LOW

?

Delay 20 ms

?

Read Again

?

Still LOW

?

Valid Press

?

Wait Until Button Release

?

Return TRUE

Result

One physical press generates one software event.

---

# Relay Operation

Button Press

?

Relay ON

?

40 ms

?

Relay OFF

Current pulse width

40 ms

Future versions

40

50

60

70

80

ms

Selectable using mode button.

---

# Design Decisions

Why Bare Metal?

Provides complete hardware control.

No dependency on vendor libraries.

Improves understanding of STM8 peripherals.

Easy to port to other STM8 devices.

---

Why Drivers?

Keeps application clean.

Improves code reuse.

Reduces maintenance.

Supports future expansion.

---

Why Modules?

Every module has only one responsibility.

GPIO

Only GPIO

Button

Only Button

Timer

Only Timer

Relay

Only Relay

QuickShifter

Only application logic

This follows the Single Responsibility Principle.

---

# Current Firmware Flow

Power ON

?

Clock Initialization

?

GPIO Initialization

?

Button Initialization

?

Timer Initialization

?

Relay Initialization

?

Infinite Loop

?

Button Press ?

?

No

?

Repeat

?

Yes

?

Relay ON

?

40 ms Delay

?

Relay OFF

?

Repeat

---

# Current Status

Completed

? GPIO Driver

? Button Driver

? Software Debounce

? Clock Configuration

? TIM4 Delay

? Relay Driver

? QuickShifter Application Layer

Hardware Tested

? Button

? Relay Module

? 40 ms Pulse

Pending

? Non-blocking State Machine

? EEPROM

? Shift Modes

? Trigger Filtering

? Final PCB

---

# Lessons Learned

1. Always initialize the clock before timers.

2. Keep GPIO access inside dedicated drivers.

3. Separate hardware drivers from application logic.

4. Debounce should be handled inside the button driver.

5. Application code should remain hardware independent.

---

# Version

Firmware Version

v0.1

Author

Rajkiran Shinde

Project

Quick Shifter Firmware

Date

August 2026

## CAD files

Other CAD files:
quickshifter.stp

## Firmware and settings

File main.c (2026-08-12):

#include "gpio.h"
#include "button.h"
#include "timer.h"
#include "config.h"
#include "clock.h"
#include "quickshifter.h"
#include "software_timer.h"
#include "mode.h"
#include "eeprom.h"
#include "watchdog.h"
#include "led.h"
#include "buzzer.h"
#include "debug.h"

int main(void)
{
    CLK_Init();
    Timer_Init();

    Button_Init();
    ModeButton_Init();

    Debug_Init();

    /* Initializes mode LEDs and turns the PC6 system LED ON. */
    LED_Init();

    Buzzer_Init();
    EEPROM_Init();

    Mode_Init();

    LED_Mode_Display(Mode_Get() + 1);

    Debug_LogMode(
        Mode_Get(),
        Mode_GetCutTime()
    );

    QuickShifter_Init();

    Buzzer_Play(BUZZER_EVENT_BOOT);

    Watchdog_Init();

    __asm ("rim\n");

    while(1)
    {
        Button_Update();
        ModeButton_Update();

        if(ModeButton_GetPress())
        {
            Mode_Next();

            LED_Mode_Display(
                Mode_Get() + 1
            );

            Buzzer_Play(
                BUZZER_EVENT_MODE_CHANGE
            );

            Debug_LogMode(
                Mode_Get(),
                Mode_GetCutTime()
            );
        }

        QuickShifter_Task();
        Buzzer_Task();
        Watchdog_Refresh();
    }
}

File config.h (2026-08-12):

#ifndef CONFIG_H
#define CONFIG_H

#include "gpio.h"

#define DEBUG_UART_ENABLED    1
#define DEBUG_BAUDRATE        9600

#define RELAY_PORT            PORT_D
#define RELAY_PIN             PIN2

#define BUTTON_PORT           PORT_D
#define BUTTON_PIN            PIN3

#define MODE_BUTTON_PORT      PORT_D
#define MODE_BUTTON_PIN       PIN4

#define BUTTON_DEBOUNCE_TIME 20

/* Mode indicator LEDs */
#define MODE_LED1_PORT       PORT_D
#define MODE_LED1_PIN        PIN6

#define MODE_LED2_PORT       PORT_A
#define MODE_LED2_PIN        PIN1

#define MODE_LED3_PORT       PORT_C
#define MODE_LED3_PIN        PIN3

#define MODE_LED4_PORT       PORT_C
#define MODE_LED4_PIN        PIN4

#define MODE_LED5_PORT       PORT_C
#define MODE_LED5_PIN        PIN5

/* System LED
 * Single LED:
 * Anode -> 3.3V
 * Cathode -> PC6
 * LOW = ON, HIGH = OFF
 *
 * PB4 and PC7 are not used by the LED driver.
 */
#define SYSTEM_LED_PORT      PORT_C
#define SYSTEM_LED_PIN       PIN6

#define BUZZER_PORT          PORT_A
#define BUZZER_PIN           PIN3

#define QS_MODE_COUNT        5
#define QS_MODE_1_TIME       40
#define QS_MODE_2_TIME       50
#define QS_MODE_3_TIME       60
#define QS_MODE_4_TIME       70
#define QS_MODE_5_TIME       80

#define WATCHDOG_TIMEOUT_MS  1000

#endif /* CONFIG_H */

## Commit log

2026-08-07 Phase 1 GPIO, Button Interface, Relay Pulse & Timer Validation
    [quickshifter.stp]
2026-08-07 Part 2 – Firmware Architecture & Non-Blocking System implemented the System and software timer, as well as a state machine
    [quickshifter.stp]
2026-08-08 UART Debug, Mode Selection and Config timing Shift control added
    [quickshifter.stp]
2026-08-08 Updated the Firmware sefaty and Watchdog timer
    [quickshifter.stp]
2026-08-08 Added the LED's for each mode
2026-08-09 Updated led driver for the system status led's and added the buzzer driver to drive the passive buzzer with different tunes for each action, startup, shift, mode shift
    [quickshifter.stp]
2026-08-09 Updated Readme for Led and Buzzer Driver
